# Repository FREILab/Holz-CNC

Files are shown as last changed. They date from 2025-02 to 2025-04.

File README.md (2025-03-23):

# Holz-CNC Elektronik

Dieses Repository dient der Dokumentation des Elektronik Aufbaus unserer Holz-CNC.

Unter "Rechnungen" befinden sich die Rechnungen mit allen bestellten Teilen.

Unter "HW" sind der Schaltplan und die 3D-Druckteile zu finden. Der Schalplan wurde mit [QElectroTech](https://qelectrotech.org/) erstellt.

[Original CNC + Controller](https://makerstore.krilano.com/product/full-parts-bundle-to-build-an-x-carve-style-cnc/)

Main Idea
========= 

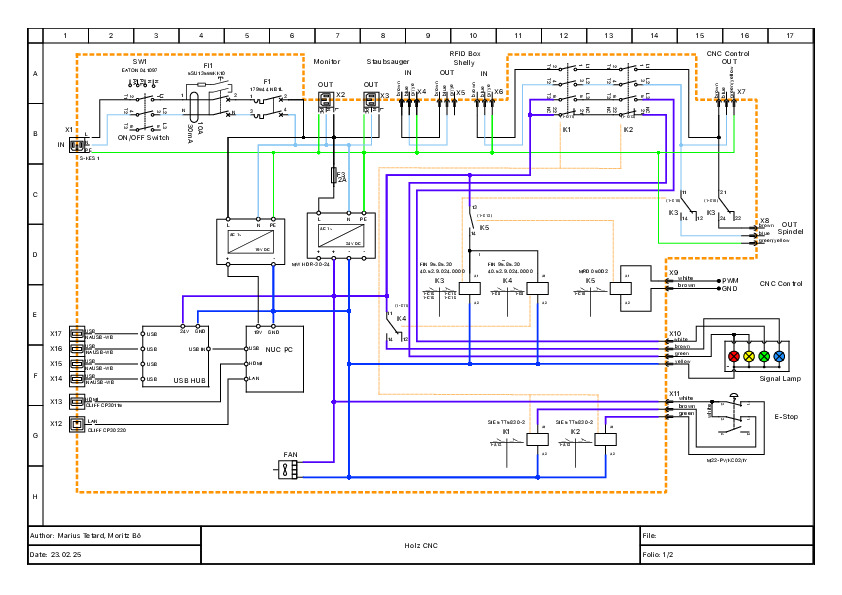
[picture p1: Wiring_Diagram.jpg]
Schaltplan


Fragen ?
========

Bei Fragen wendet euch bitte an das Holz-CNC Team (Slack/Mattermost) oder die Maintainer dieses Repos.

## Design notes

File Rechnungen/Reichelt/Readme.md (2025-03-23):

Fehlbestellung
==============

Das Schütz von Siemens (Artikel-Nr.: SIE 5TT5830-2 INSTA-Schütz 4 NO, 24 V AC / 25 A) war eine Fehlbestellung da es 24V AC für die Spule benötigt und wir 24DC brauchen. Darum gab es eine Retourensendung von uns zu Reichelt. Die neuen Schütze wurdn bei Schütz24 bestellt.

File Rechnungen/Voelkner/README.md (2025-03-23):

Fehlbestellung
==============

Sicherung X646191 PÜSCHEL Sicherung flink 6,3 x 32 mm 2 A war eine Fehlbestellung. Die Sicherung war zu Groß.

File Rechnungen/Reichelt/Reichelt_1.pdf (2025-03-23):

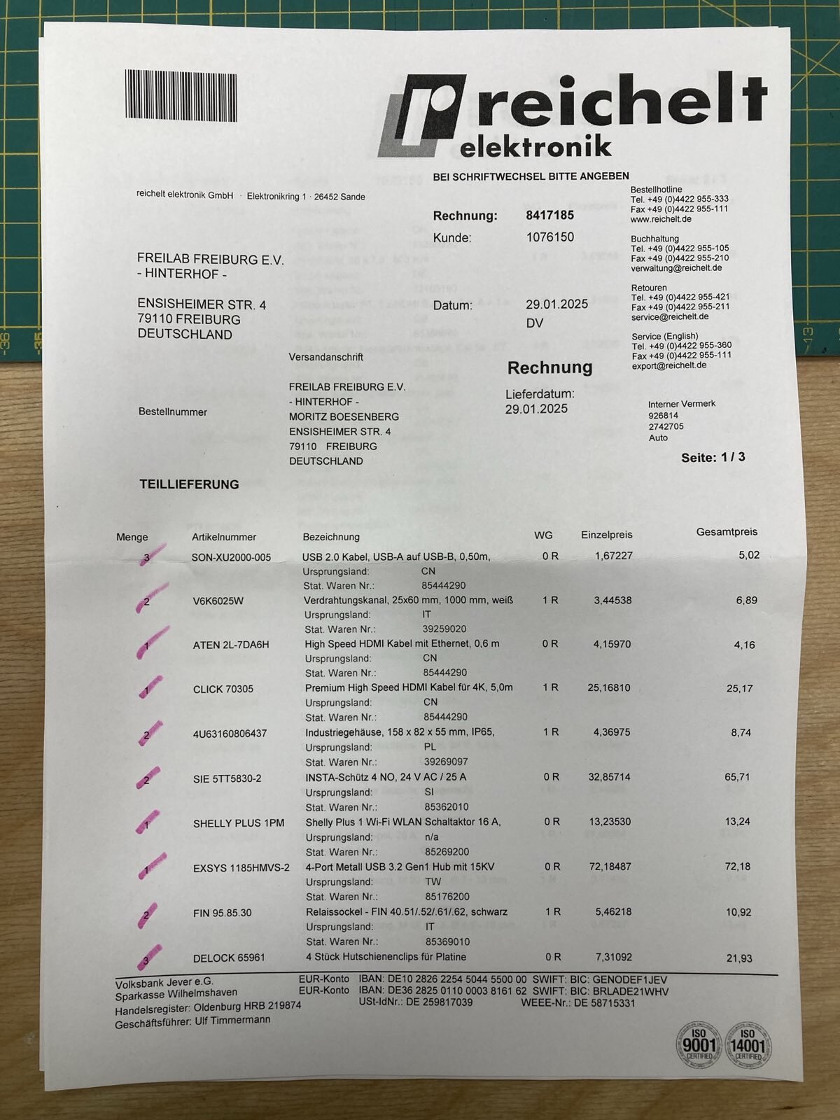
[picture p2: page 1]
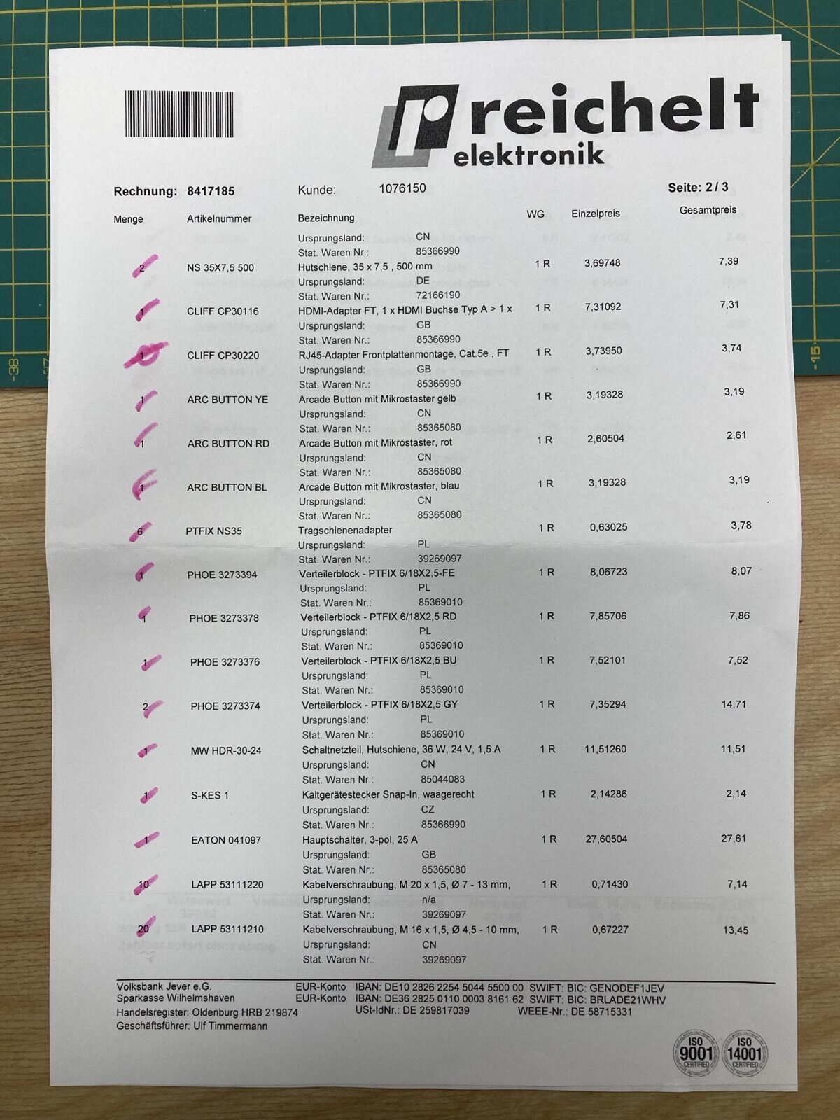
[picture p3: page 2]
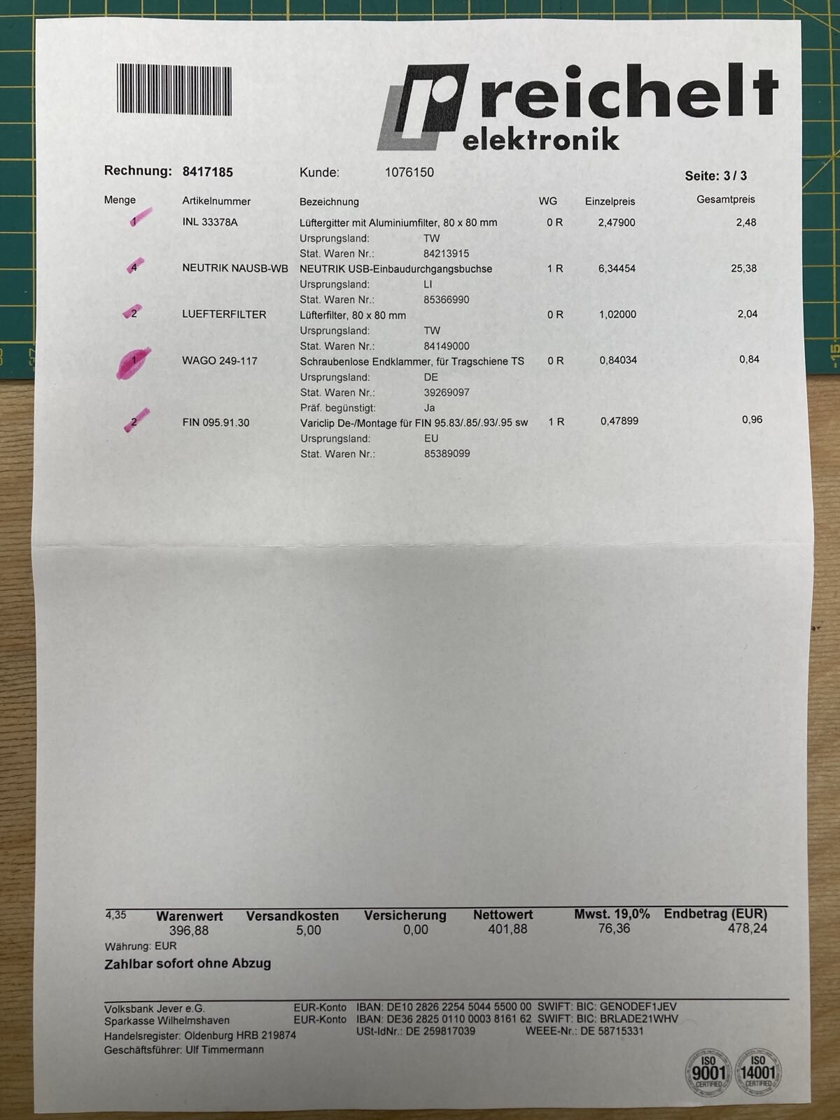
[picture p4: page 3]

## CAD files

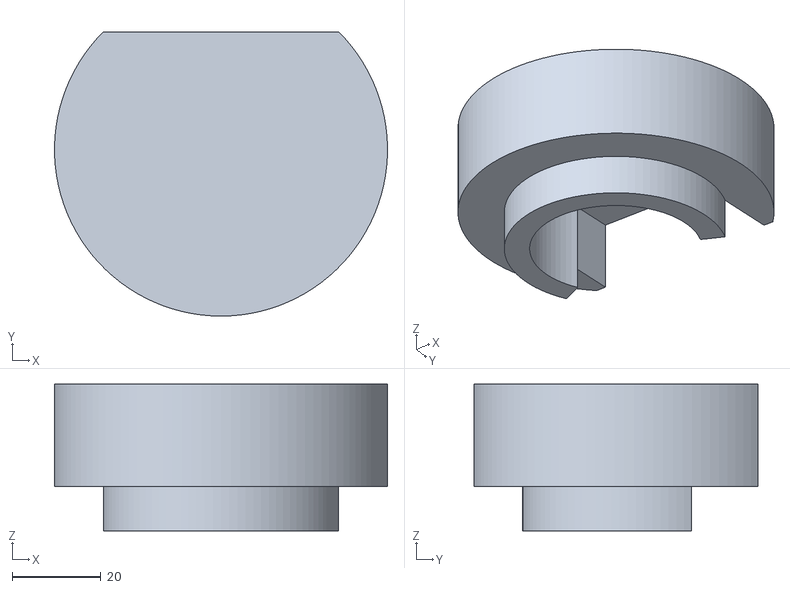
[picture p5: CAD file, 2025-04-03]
HW/3D_Prints/Kabeldruchführung.stl
75.0 x 64.0 x 33.0

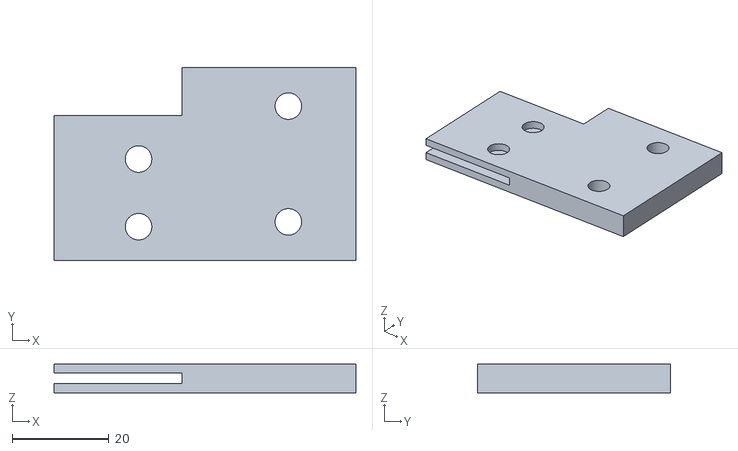
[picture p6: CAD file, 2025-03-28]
HW/3D_Prints/Schleppketten_Adapter_Y_bot.stl
62.5 x 40.0 x 6.00

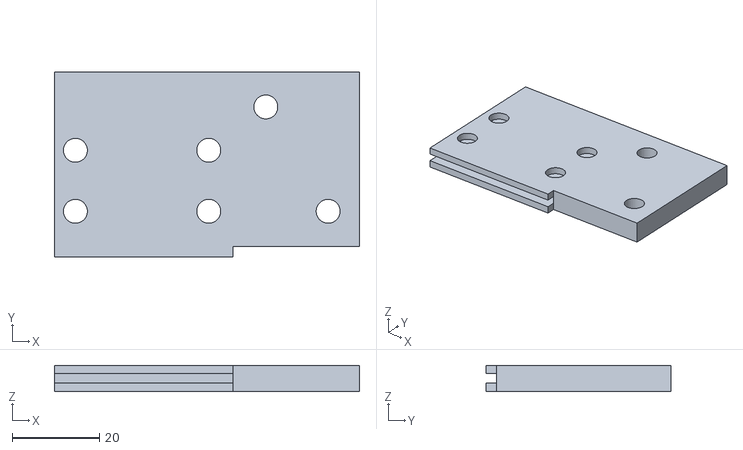
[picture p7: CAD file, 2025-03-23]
HW/3D_Prints/Schleppketten_Adapter_X_top.stl
70.0 x 42.5 x 6.00

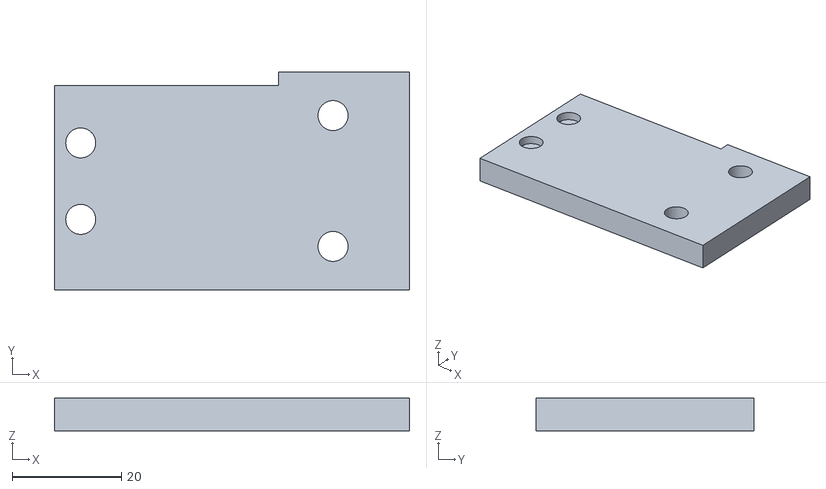
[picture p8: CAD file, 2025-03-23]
HW/3D_Prints/Schleppketten_Adapter_Y_top.stl
65.0 x 40.0 x 6.00

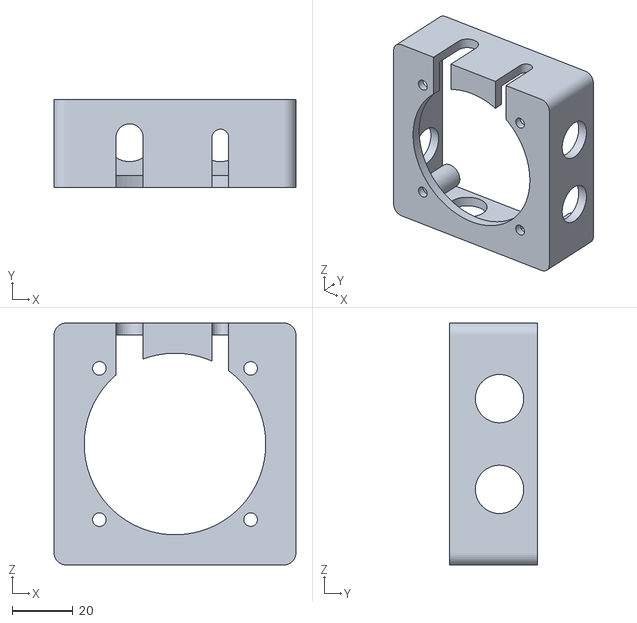
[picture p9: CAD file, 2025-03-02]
HW/3D_Prints/Wanddurchführung_bot.stl
80.0 x 29.0 x 80.0

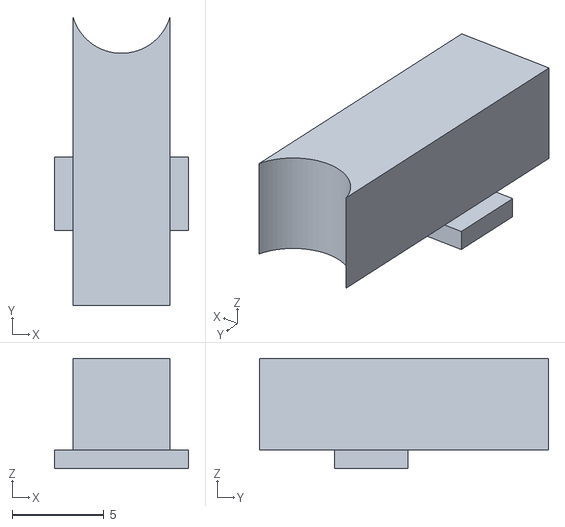
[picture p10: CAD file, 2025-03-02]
HW/3D_Prints/Wanddurchführung_cap2.stl
7.30 x 15.8 x 6.00

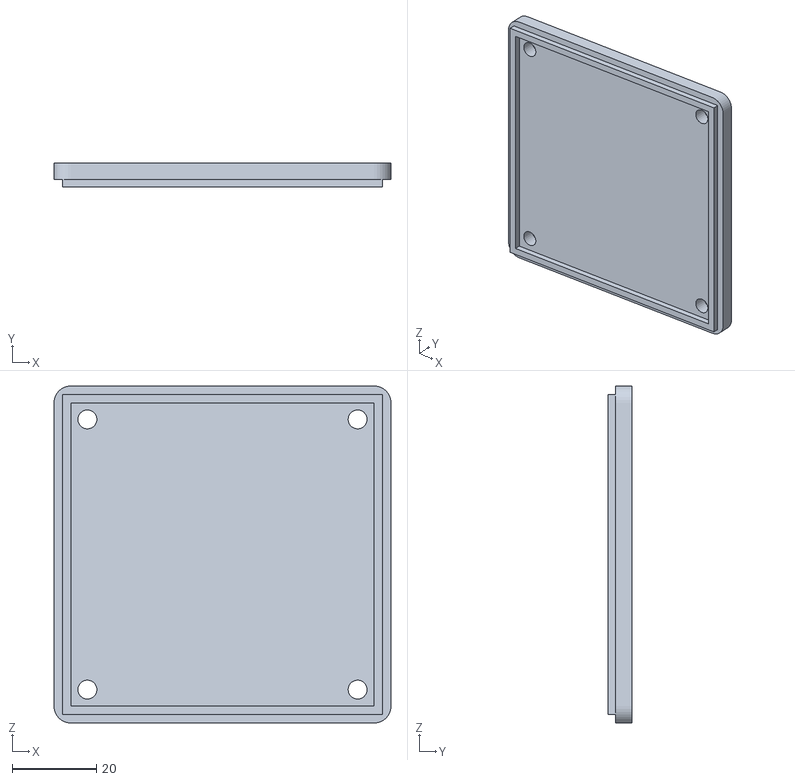
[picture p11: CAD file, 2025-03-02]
HW/3D_Prints/Wanddurchführung_top.stl
80.0 x 5.80 x 80.0

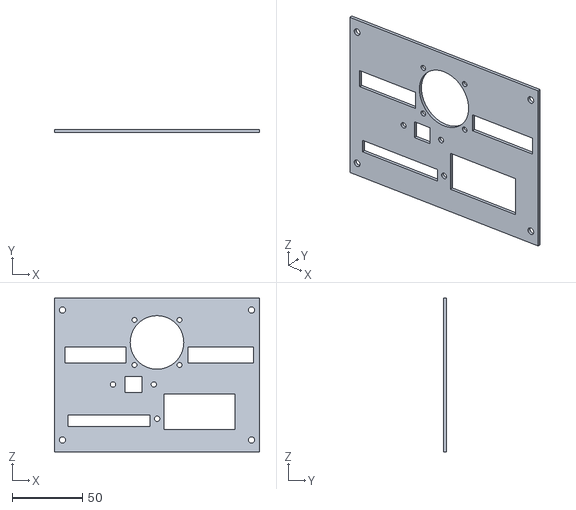
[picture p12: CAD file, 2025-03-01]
HW/3D_Prints/CNC_Control_Panel_bot.stl
145.5 x 2.00 x 109.0

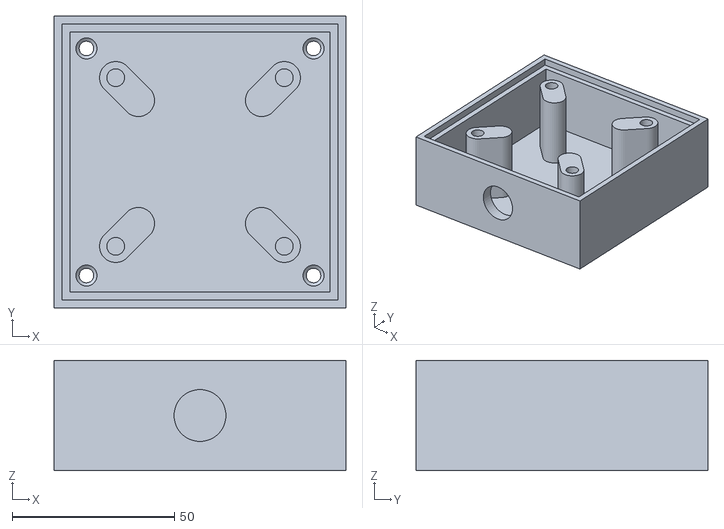
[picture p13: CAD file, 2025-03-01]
HW/3D_Prints/Signal_Lamp_Mount_bot.stl
90.0 x 90.0 x 34.0

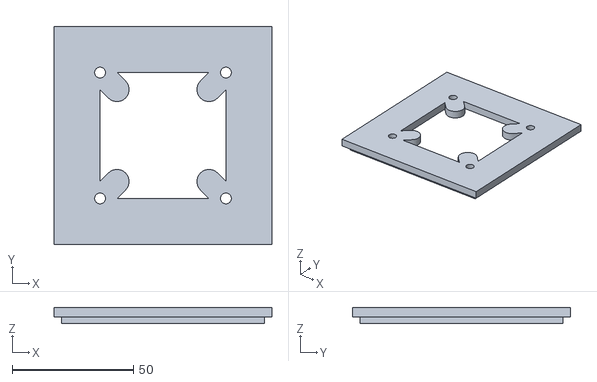
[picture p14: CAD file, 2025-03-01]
HW/3D_Prints/Signal_Lamp_Mount_top.stl
90.0 x 90.0 x 6.80

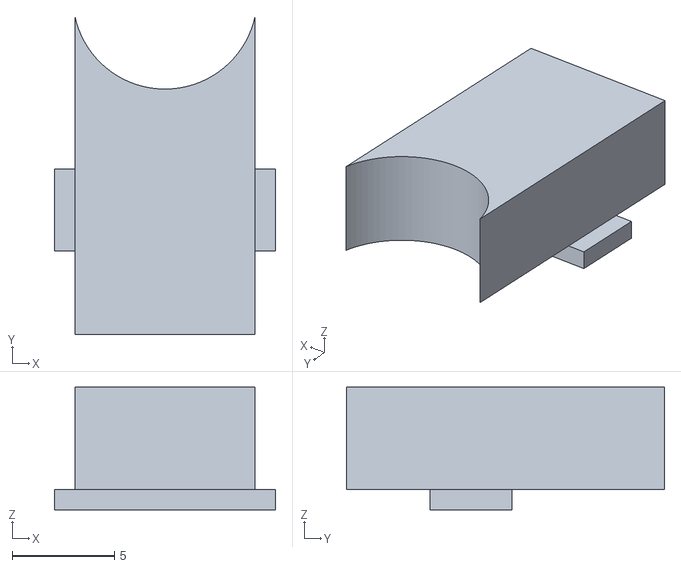
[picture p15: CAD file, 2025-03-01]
HW/3D_Prints/Wanddurchführung_cap1.stl
10.8 x 15.6 x 6.00

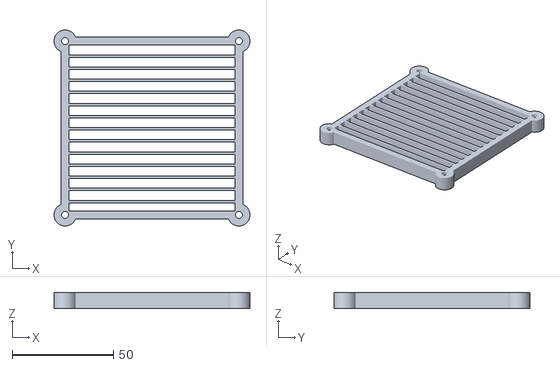
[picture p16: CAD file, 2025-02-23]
HW/3D_Prints/Fan_Mount_Cover.stl
97.0 x 97.0 x 8.00

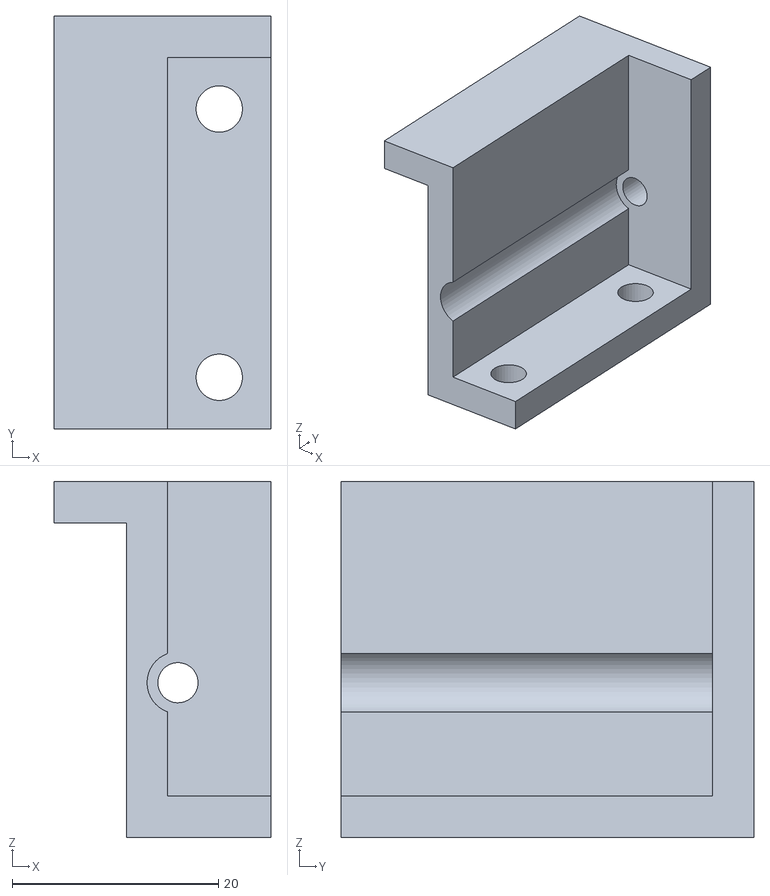
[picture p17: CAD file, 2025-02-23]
HW/3D_Prints/USB_Hub_Mount_right.stl
21.0 x 40.0 x 34.5

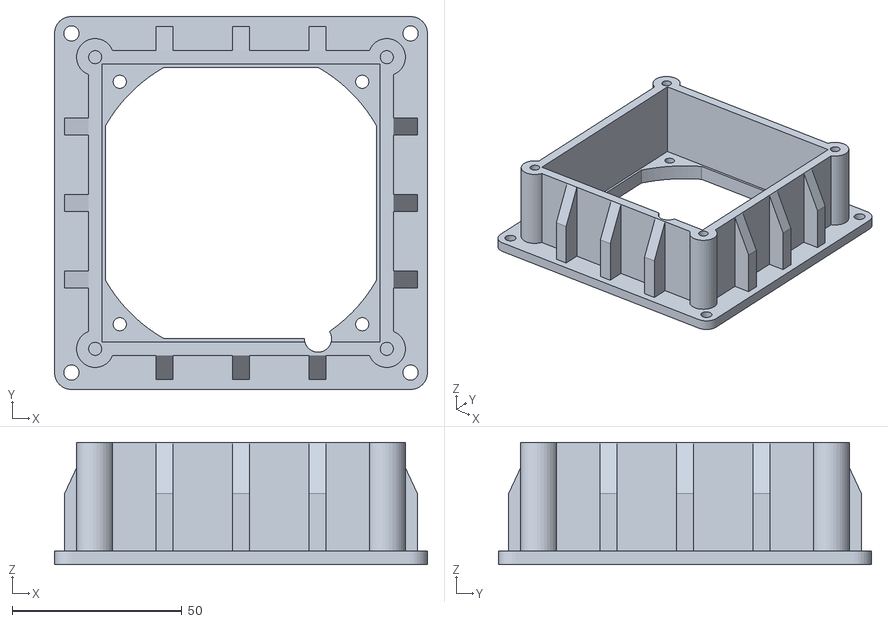
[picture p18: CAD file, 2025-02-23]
HW/3D_Prints/Fan_Mount_Base.stl
110.0 x 110.0 x 36.0

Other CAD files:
HW/3D_Prints/CNC_Control_Panel_top.stl
HW/3D_Prints/USB_Hub_Mount_left.stl
HW/3D_Prints/Fan_Mount_Filter.stl
HW/3D_Prints/NUC_Mount.stl
HW/3D_Prints/CNC_Control_Panels.f3d
HW/3D_Prints/Fan_Mount.f3d
HW/3D_Prints/Kabeldruchführung.f3d
HW/3D_Prints/M16x1.5_Nut.stl
HW/3D_Prints/M16x1.5_Plug.3mf
HW/3D_Prints/M20x1.5_Nut.stl
HW/3D_Prints/M20x1.5_Plug.3mf
HW/3D_Prints/NUC_Mount.f3d
HW/3D_Prints/Schleppketten_Adapter_X_top.f3d
HW/3D_Prints/Schleppketten_Adapter_Y_bot.f3d
HW/3D_Prints/Schleppketten_Adapter_Y_top.f3d
HW/3D_Prints/Signal_Light_Mount.f3d
HW/3D_Prints/USB_Hub_Mount.f3d
HW/3D_Prints/Wanddurchführung.f3d

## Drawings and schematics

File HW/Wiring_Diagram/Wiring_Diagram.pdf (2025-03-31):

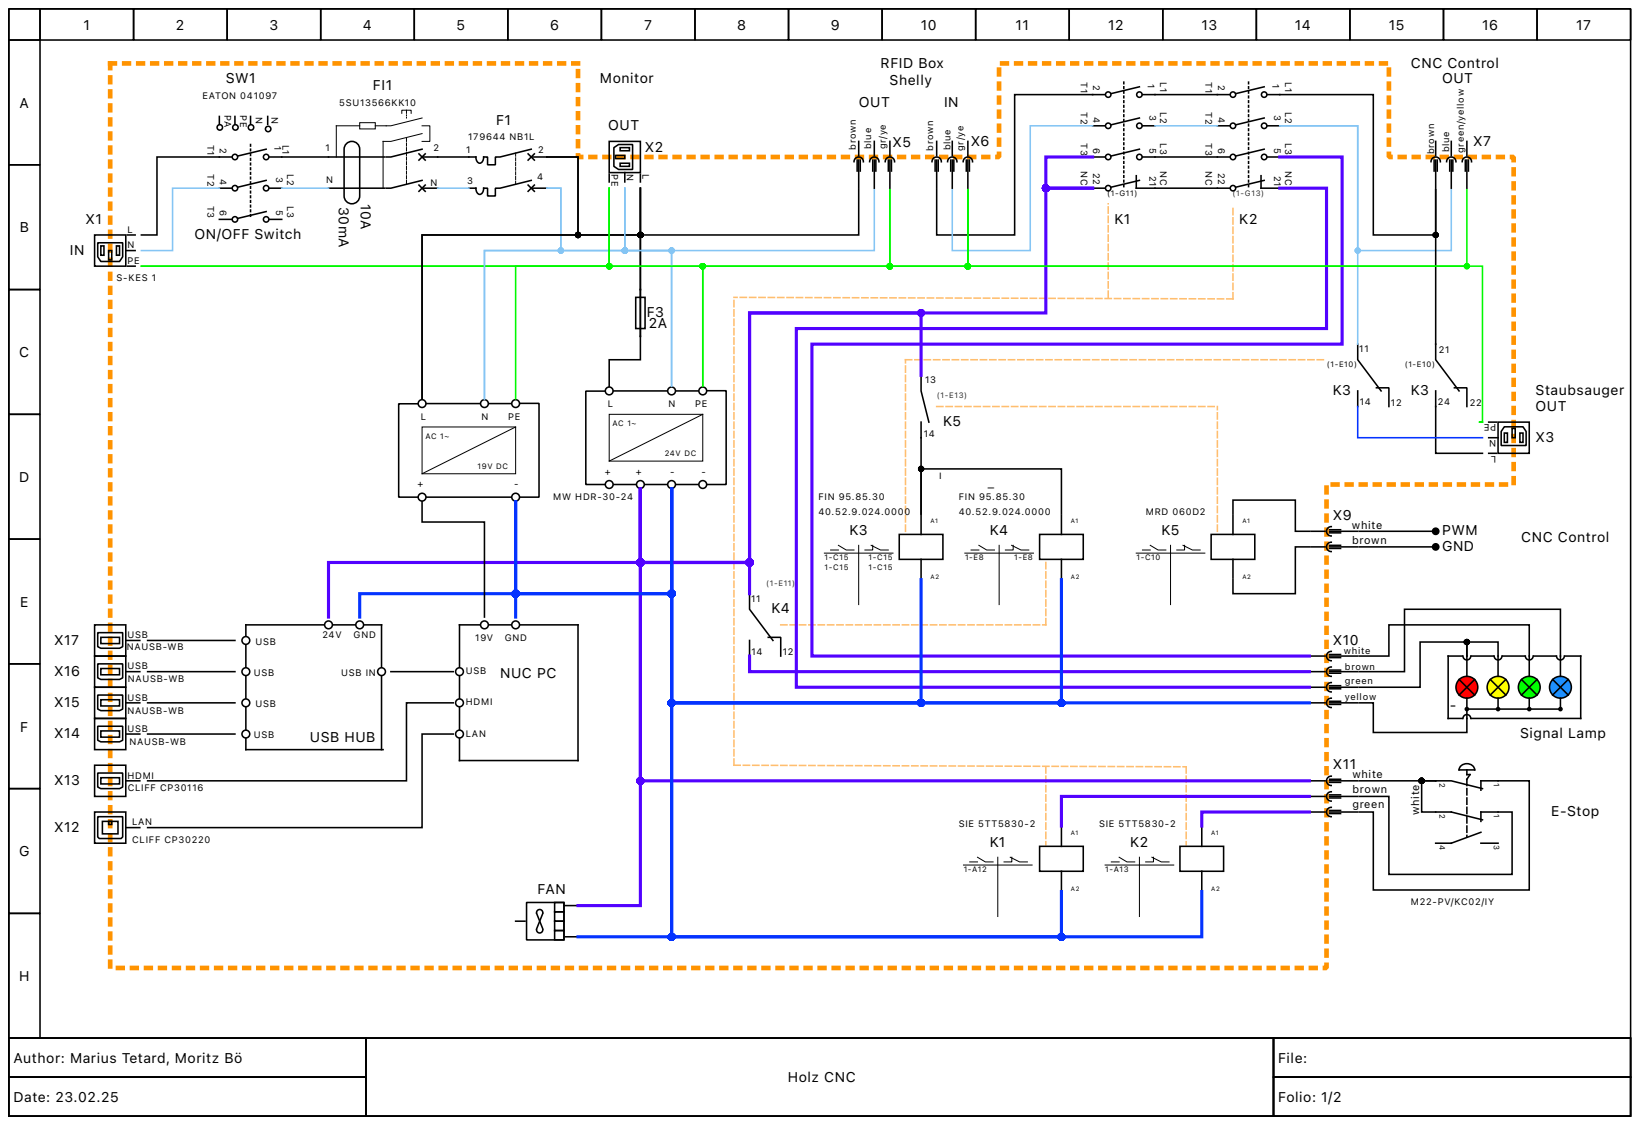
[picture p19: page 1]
Holz CNC; File:; Date: 23.02.25; Folio: 1/2; blue; FIN 95.85.30 40.52.9.024.0000; brown; USB NAUSB-WB; LAN; GND; USB; HDMI; NUC PC; MW HDR-30-24; white; green; S-KES 1; HDMI CLIFF CP30116; SIE 5TT5830-2; EATON 041097; green/yellow; CLIFF CP30220; yellow; FAN; FIN 95.85.30; MRD 060D2; USB IN; USB HUB; PWM; Staubsauger; CNC Control; RFID Box Shelly; OUT; E-Stop; Signal Lamp; Monitor; whit

ON/OFF Switch

Author: Marius Tetard, Moritz Bö

## 2mis

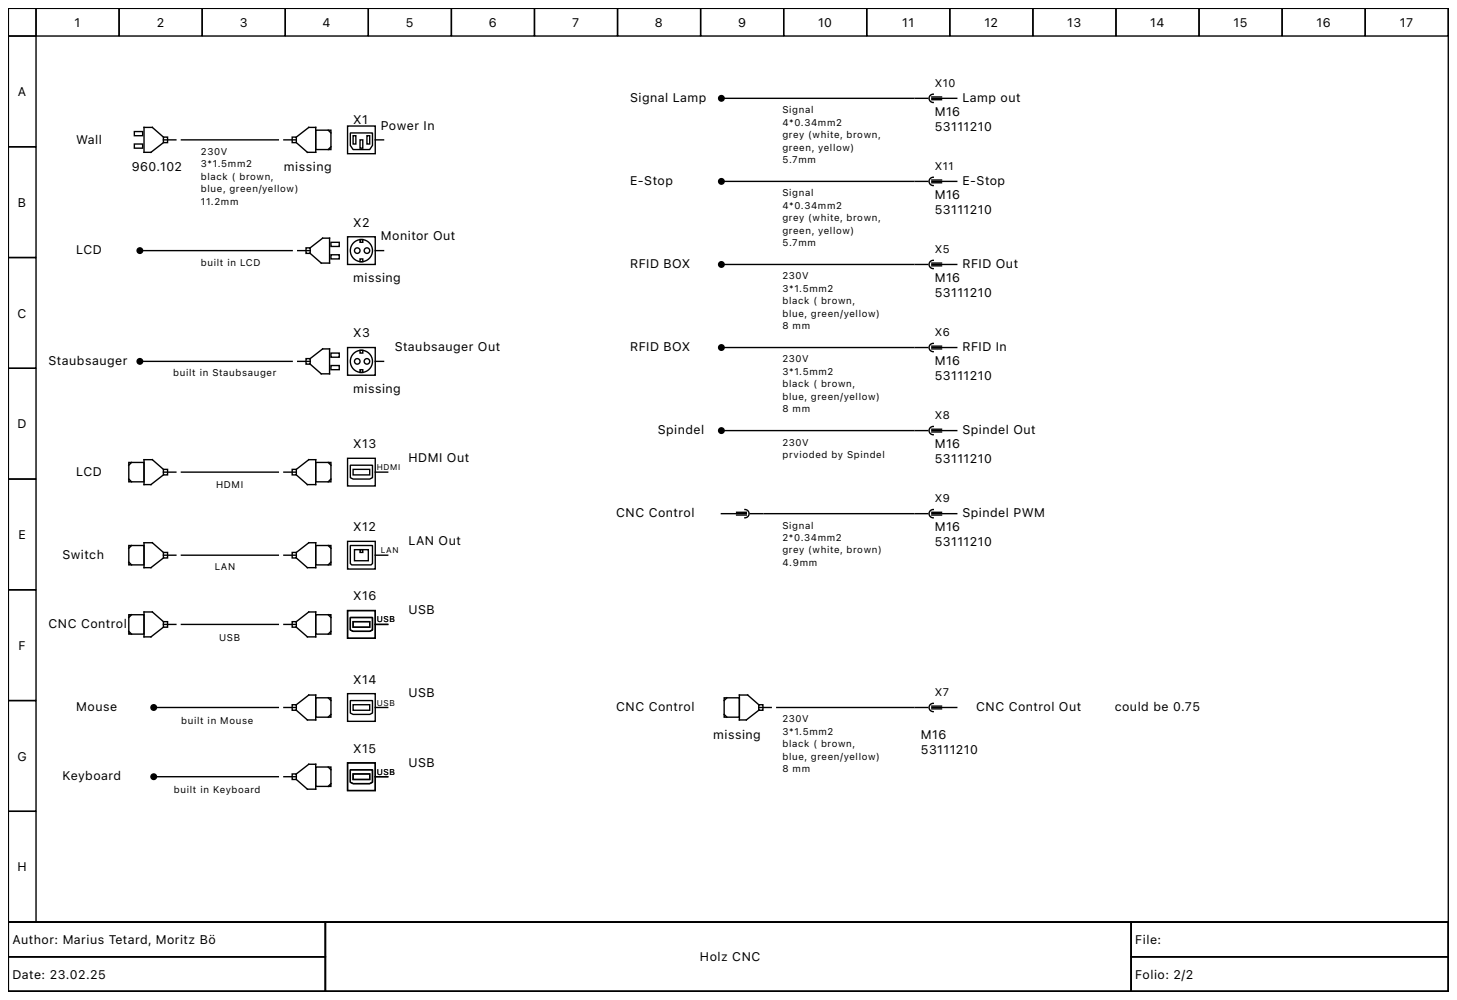
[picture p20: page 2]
ABCDEFGHAu; riu; rit; olz; File: Date: 23.02.25; Folio: 2; sin; mis; 3mis; wit; pin; FID In; Sig; FID; all; nit; ol LCD; uld; hit; ello; uilt in; bla; blu; MI USB; vio

el built in Staubsauger

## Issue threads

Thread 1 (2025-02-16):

Kabel bestellen

lemmi25, 2025-02-16:
Kabel bestellen die für die Schrittmotoren passen.

[Link zu Kabel](https://www.voelkner.de/products/5708/LAPP-26102-1-Schleppkettenleitung-OeLFLEX-FD-CLASSIC-810-4G-0.50mm-Grau-Meterware.html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)

im Idealfall können wir mehr Kabel bestellen und es kann auch beim Lasercutter eingestzt werden.

mariuste, 2025-02-18:
in #4 hinterlegt

Closed 2025-02-18.

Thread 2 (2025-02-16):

Schütze umtauschen neu bestellen

lemmi25, 2025-02-16:
Die aktuellen Schütze haben Spulen die mit 24V AC funktionieren. Wir brauchen aber 24V DC Spulen.

Alte Spulen umtauschen und neue bestellen.

[Link zu neuen Spulen](https://www.schuetze24.com/mini-schuetze/mini-leistungsschuetze/mini-leistungsschuetz-k1-09d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)

lemmi25, 2025-02-18:
Neue Schütze sind bestellt.

Closed 2025-02-18.

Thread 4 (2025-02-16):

Bestellung (fehlende Bauteile)

lemmi25, 2025-02-16:
Voelkner
- [x] [Endklammer Grau](https://www.voelkner.de/products/44864/WAGO-249-117-Endklammer-Grau.html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) 10x
- [x] [Netzfilter](https://www.voelkner.de/products/7286851/TRU-COMPONENTS-TC-10101440-Netzfilter-mit-Kaltgeraetebuchse-250-V-AC-10A-0.3-mH-L-x-B-x-H-58-x-50-x-22.8mm-1St..html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)
- [x] [Kabel für Schrittmotoren 4 Adern 0.5mm, 6.80 Durchmesser](https://www.voelkner.de/products/5708/LAPP-26102-1-Schleppkettenleitung-OeLFLEX-FD-CLASSIC-810-4G-0.50mm-Grau-Meterware.html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) siehe #1  Biegeradius 7.5 x Außendurchmesser
- [x] [Kabel für Schrittmotoren 2 Adern 0.5mm, 5.80 Durchmesser](https://www.voelkner.de/products/6600/LAPP-26100-1-Schleppkettenleitung-OeLFLEX-FD-CLASSIC-810-2-x-0.5mm-Grau-Meterware.html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) Biegeradius 7.5 x Außendurchmesser
- [x] [Lüfter](https://www.voelkner.de/products/10878910/SEPA-MFB40H24A-001-Axialluefter-24-V-DC-11.28-m-h-L-x-B-x-H-40-x-40-x-10mm.html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) für CNC Steuerung
- [ ] [Lüfter Gitter 40mm](https://www.reichelt.de/de/de/shop/produkt/lueftergitter_mit_aluminiumfilter_40_x_40_mm-150101#closemodal)
- [x]  [Schlagschutz Lüfter 40mm](https://www.reichelt.de/de/de/shop/produkt/schutzgitter_fuer_luefter_40x40mm-11016)
- [x] [Schutzkontakt Stecker für Display](https://www.voelkner.de/products/1247997/Bachmann-913.173-Schutzkontaktstecker-Gummi-Silikon-250-V-Schwarz-IP44.html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)
- [x] [Langes Stromkabel für den Monitor](https://www.voelkner.de/products/942940/LogiLink-Kaltgeraete-Anschlusskabel-1x-Schutzkontakt-Stecker-1x-Kaltgeraete-Buchse-C13-5.00-m-Schwarz.html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)
- [x] [Fehlendes internes USB Kabel](https://www.voelkner.de/products/11837703/Delock-USB-Kabel-USB-2.0-USB-A-Stecker-USB-B-Stecker-0.5m-Schwarz-83684.html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)
- [x] [Externe USB Verlängerungskabel um HUB anzuschließen](https://www.voelkner.de/products/1959975/USB-3.0-SuperSpeed-Verlaengerungskabel-Schwarz-Gesamtlaenge-3-Meter-deutlich-schneller-als-USB-2.0.html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)

Igus
- [x]  [Energiekette 1](https://www.igus.de/product/series-E2-17?artnr=E2.17.038.063.0) mit 17mm und 38mm Innenbreite 900 mm Verfahrweg
- [x]  [Energiekette 2](https://www.igus.de/product/series-E2-21?artnr=E2.21.038.035.0) mit 21mm und 38mm Innenbreite 1200 mm Verfahrweg

lemmi25, 2025-03-02:
Hey,

@mariuste kannst du noch die Dinge eintragen die genau bestellt werden müssen (z.B. Lüftergröße) ?
Kannst du bitte auch einmal die Größe der Energiekette ausmessen? (Bin leider krank geworden und kann heute nicht ins Lab)
Ich habe heute morgen noch einmal mit Finn telefoniert. Wir würden noch Enrgieketten und neue Kabel bestellen (nachdem ich noch einmal geschaut habe was es kosten würde). Sollte noch im Budget sein (vom Tisch). Ich würd die neuen Kabel mit einem Stecker (den wir bestimmt irgendwo im Lab haben?, habe auch schon Olaf geschrieben und gefragt) an die Nema 23 Stecken. Also so das wir die gecrimpten Kabel beibehalten.

Was denkst du dazu?

Beste Grüße

Moritz

mariuste, 2025-03-02:
Moin,
kann ich versuchen, aber ich glaube dass ich nicht heute dazu komme, da ich an der RFID Box arbeite. Vielleicht kann ich es einschieben.

lemmi25, 2025-03-04:
Brauchen wir den Netzfilter noch [Netzfilter](https://www.voelkner.de/products/7286851/TRU-COMPONENTS-TC-10101440-Netzfilter-mit-Kaltgeraetebuchse-250-V-AC-10A-0.3-mH-L-x-B-x-H-58-x-50-x-22.8mm-1St..html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)? [Lüfter Gitter 40mm](https://www.reichelt.de/de/de/shop/produkt/lueftergitter_mit_aluminiumfilter_40_x_40_mm-150101#closemodal) Diesen Posten gibt es leider nicht bei Voelkner und ich müsste nur dafür bei Reichelt bestellen. Kommst du auch ohne aus?

mariuste, 2025-03-04:
Auf Netzfilter können wir verzichten; könnte man auch irgendwann nachrüsten. Den filter kann ich besorgen.

mariuste, 2025-03-07:
Hast du auch die USB-Verlängerung bestellt? Die war nicht auf dem Lieferschein

mariuste, 2025-03-07:
@lemmi25 Hast du auch die USB-Verlängerung bestellt? Die war nicht auf dem Lieferschein

Closed 2025-03-09.

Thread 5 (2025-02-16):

LED Streifen bestellen

lemmi25, 2025-02-16:
Rote und Grüne Led Streifen bestellen (für Notaus, siehe #3 #4  ). To be discussed ...

mariuste, 2025-02-17:
Am besten Maschinen Indikator, z.B. https://amzn.eu/d/fziliju 2 Stufen, 24V ohne Summer (rot/grün)

rot: schütz nicht aktiv, grün schütz aktiv

mariuste, 2025-02-18:
in #4 überführt

Closed 2025-02-18.

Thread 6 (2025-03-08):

TODO: RefineCircuit Diagram

mariuste, 2025-03-08:
- [ ] Füge QR Code auf extra Seite hinzu
- [ ] korrigiere usb mit externen hub
- [ ] Designe blatte hater für das innere der Box
- [ ] Drucke Schaltplan aus und lege ihn in die box

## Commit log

2025-02-17 add FI and Fuse
2025-02-17 added back connectors
2025-02-17 add power supply type
2025-02-18 finished wiring diagram
2025-02-19 changed colors of 24V and GND
2025-02-20 änderung der ersten korrekten Bestellung von Voelkner
2025-02-23 add 3d models
    [CNC_Control_Panel_top.stl, Fan_Mount.f3d, Fan_Mount_Base.stl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]
2025-03-01 2mm fix
    [CNC_Control_Panel_bot.stl, CNC_Control_Panels.f3d]
2025-03-02 minor fix
    [Wanddurchführung.f3d, Wanddurchführung_bot.stl, Wanddurchführung_cap1.stl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]
2025-03-23 add sleppketten mount
    [Schleppketten_Adapter_X_top.f3d, Schleppketten_Adapter_X_top.stl, Schleppketten_Adapter_Y_top.f3d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]
2025-03-28 add adapter
    [Schleppketten_Adapter_Y_bot.f3d, Schleppketten_Adapter_Y_bot.stl]
2025-04-03 add kabeldurchführung
    [Kabeldruchführung.f3d, Kabeldruchführung.stl]
2026-10-29 Merge PiBot/FluidNC controller into Holz-CNC
    Umbau 2026: the stock X-Carve controller was replaced by a PiBot V5.88
    Ultra with FluidNC and 4x TMC5160, the router by an AMB FME-1050W.
    This repo is now the single source of truth for the machine.
    - Controller/: FluidNC config (taken over from FREILab/fluidnc-configs),
    examples, postprocessors, validator, firmware notes
    - HW/Verdrahtung.md: Schaltkasten wiring and PiBot interface
    - HW/Controller, HW/Spindel, HW/Datenblaetter: reference documents
    - 3D/Schaltkasten (was HW/3D_Prints) and 3D/Pibot-Kasten (new case)
    - Rechnungen/PiBot: PiBot invoice
    - Wiring_Diagram.jpg regenerated from the current PDF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
2026-10-29 Werkzeugbibliotheken für Fusion 360 und Estlcam
    Fräserinventar plus generierte Bibliotheken für die 8 SpeTool-Fräser mit
    den Profilen Schaumstoff, MDF, Multiplex und Hartholz. generate.py baut
    Fusion-JSON, Estlcam-CSV und Schnittdaten.md aus der SpeTool-Datenbank
    und den Feed&Speed-PDFs (Quellen/), abgemindert für die X-Carve.
    Coolant ist "disabled", weil freilab-fluidnc.cps nur Flood/Off kennt.
    "tool-block": null aus der SpeTool-DB wird entfernt, sonst meldet Fusion
    "missing required data".
